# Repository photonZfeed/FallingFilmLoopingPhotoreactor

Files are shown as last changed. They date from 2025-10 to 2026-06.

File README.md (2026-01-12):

# Falling Film Looping Photoreactor and Residence Time Distribution Measurement Cells

A modular and characterized open source Falling Film Looping Photoreactor (FFLPR) concept for Automated Batch Stirred Tank Reactor (ABSTR) and Contineous Stirred Tank Reactor (CSTR) operation. And a Residence Time Distribution (RTD) cell for puls tracer measurements.

## Documentation

3D CAD files for the RTD cell manufacturing are documented in the [CAD section](./00_CAD/).

Experimental raw data on the RTD and bromination experiments are provided in the [Experiments section](./01_Experiments/).

A detailed documentation of the RTD cells and photoreactor including its control software as well as the RTD model are available under https://photonzfeed.github.io/FallingFilmLoopingPhotoreactor/.

## Folder Structure

```
📦Falling_Film_Loop_Photoreactor_RTD
┣ 📂 00_CAD
┃  ┣ 📜 RTD_cell_bottom_1mm_tubing.ipt
┃  ┣ 📜 RTD_cell_bottom_1mm_tubing.stl
┃  ┣ 📜 RTD_cell_bottom_2mm_tubing.ipt
┃  ┣ 📜 RTD_cell_bottom_2mm_tubing.stl
┃  ┣ 📜 RTD_cell_bottom_3mm_tubing.ipt
┃  ┣ 📜 RTD_cell_bottom_3mm_tubing.stl
┃  ┣ 📜 RTD_cell_top_1mm_tubing.ipt
┃  ┣ 📜 RTD_cell_top_1mm_tubing.stl
┃  ┣ 📜 RTD_cell_top_2mm_tubing.ipt
┃  ┣ 📜 RTD_cell_top_2mm_tubing.stl
┃  ┣ 📜 RTD_cell_top_3mm_tubing.ipt
┃  ┗ 📜 RTD_cell_top_3mm_tubing.stl
┣ 📂 01_Experiments
┃  ┣ 📂 00_RTD
┃  ┃  ┣ 📂 00_External_Flow_Rate_Variation
┃  ┃  ┃  ┣ 📜 03.3 mL per min.csv
┃  ┃  ┃  ┣ 📜 05 mL per min.csv
┃  ┃  ┃  ┣ 📜 10 mL per min.csv
┃  ┃  ┃  ┣ 📜 20 mL per min.csv
┃  ┃  ┃  ┗ 📜 40 mL per min.csv
┃  ┃  ┗ 📂 01_Space_Velocity_Variation
┃  ┃     ┣ 📜 0spv.csv
┃  ┃     ┣ 📜 15spv.csv
┃  ┃     ┣ 📜 30spv.csv
┃  ┃     ┗ 📜 5spv.csv
┃  ┗ 📂 01_Bromination
┃     ┣ 📂 00_CSTR_PLC_New_Column
┃     ┃  ┣ 📂 EXP-3 10 mLmin-1 external flow rate
┃     ┃  ┃  ┣ 📜 1.pdf
┃     ┃  ┃  ┣ 📜 10.pdf
┃     ┃  ┃  ┣ 📜 11.pdf
┃     ┃  ┃  ┣ 📜 12.pdf
┃     ┃  ┃  ┣ 📜 13.pdf
┃     ┃  ┃  ┣ 📜 14.pdf
┃     ┃  ┃  ┣ 📜 15.pdf
┃     ┃  ┃  ┣ 📜 2.pdf
┃     ┃  ┃  ┣ 📜 3.pdf
┃     ┃  ┃  ┣ 📜 4.pdf
┃     ┃  ┃  ┣ 📜 5.pdf
┃     ┃  ┃  ┣ 📜 6.pdf
┃     ┃  ┃  ┣ 📜 7.pdf
┃     ┃  ┃  ┣ 📜 8.pdf
┃     ┃  ┃  ┗ 📜 9.pdf
┃     ┃  ┣ 📂 EXP-4 20 mLmin-1 external flow rate
┃     ┃  ┃  ┣ 📜 1.pdf
┃     ┃  ┃  ┣ 📜 10.pdf
┃     ┃  ┃  ┣ 📜 11.pdf
┃     ┃  ┃  ┣ 📜 12.pdf
┃     ┃  ┃  ┣ 📜 13.pdf
┃     ┃  ┃  ┣ 📜 14.pdf
┃     ┃  ┃  ┣ 📜 15.pdf
┃     ┃  ┃  ┣ 📜 2.pdf
┃     ┃  ┃  ┣ 📜 3.pdf
┃     ┃  ┃  ┣ 📜 4.pdf
┃     ┃  ┃  ┣ 📜 5.pdf
┃     ┃  ┃  ┣ 📜 6.pdf
┃     ┃  ┃  ┣ 📜 7.pdf
┃     ┃  ┃  ┣ 📜 8.pdf
┃     ┃  ┃  ┗ 📜 9.pdf
┃     ┃  ┣ 📂 EXP-5 40 mLmin-1 external flow rate
┃     ┃  ┃  ┣ 📜 1.pdf
┃     ┃  ┃  ┣ 📜 10.pdf
┃     ┃  ┃  ┣ 📜 11`.pdf
┃     ┃  ┃  ┣ 📜 12.pdf
┃     ┃  ┃  ┣ 📜 13.pdf
┃     ┃  ┃  ┣ 📜 14.pdf
┃     ┃  ┃  ┣ 📜 15.pdf
┃     ┃  ┃  ┣ 📜 2.pdf
┃     ┃  ┃  ┣ 📜 3.pdf
┃     ┃  ┃  ┣ 📜 4.pdf
┃     ┃  ┃  ┣ 📜 5.pdf
┃     ┃  ┃  ┣ 📜 6.pdf
┃     ┃  ┃  ┣ 📜 7.pdf
┃     ┃  ┃  ┣ 📜 8.pdf
┃     ┃  ┃  ┗ 📜 9.pdf
┃     ┃  ┣ 📂 Scale-Up
┃     ┃  ┃  ┣ 📜 1.pdf
┃     ┃  ┃  ┣ 📜 10.pdf
┃     ┃  ┃  ┣ 📜 11.pdf
┃     ┃  ┃  ┣ 📜 12.pdf
┃     ┃  ┃  ┣ 📜 13.pdf
┃     ┃  ┃  ┣ 📜 14.pdf
┃     ┃  ┃  ┣ 📜 15.pdf
┃     ┃  ┃  ┣ 📜 2.pdf
┃     ┃  ┃  ┣ 📜 3.pdf
┃     ┃  ┃  ┣ 📜 4.pdf
┃     ┃  ┃  ┣ 📜 5.pdf
┃     ┃  ┃  ┣ 📜 6.pdf
┃     ┃  ┃  ┣ 📜 7.pdf
┃     ┃  ┃  ┣ 📜 8.pdf
┃     ┃  ┃  ┣ 📜 9.pdf
┃     ┃  ┃  ┗ 📜 BLANK.pdf
┃     ┃  ┣ 📂 Std. Graph
┃     ┃  ┃  ┣ 📜 BB1.1.pdf
┃     ┃  ┃  ┣ 📜 BB1.pdf
┃     ┃  ┃  ┣ 📜 BB2.pdf
┃     ┃  ┃  ┣ 📜 BB3.pdf
┃     ┃  ┃  ┣ 📜 BB4.pdf
┃     ┃  ┃  ┣ 📜 BB5.pdf
┃     ┃  ┃  ┣ 📜 BB6.pdf
┃     ┃  ┃  ┣ 📜 BB7.pdf
┃     ┃  ┃  ┣ 📜 BB8.pdf
┃     ┃  ┃  ┣ 📜 BB9.pdf
┃     ┃  ┃  ┗ 📜 BLANK.pdf
┃     ┃  ┗ 📜 readme.md
┃     ┣ 📂 01_CSTR_UV_VIS
┃     ┃  ┣ 📂 3 mLmin-1
┃     ┃  ┃  ┣ 📜 500 mM 3 mL-min.opju
┃     ┃  ┃  ┣ 📜 M1.txt
┃     ┃  ┃  ┣ 📜 R1.txt
┃     ┃  ┃  ┣ 📜 t=18.txt
┃     ┃  ┃  ┣ 📜 t=2.txt
┃     ┃  ┃  ┣ 📜 t=28.txt
┃     ┃  ┃  ┣ 📜 t=38.txt
┃     ┃  ┃  ┣ 📜 t=4.txt
┃     ┃  ┃  ┣ 📜 t=48.txt
┃     ┃  ┃  ┣ 📜 t=58.txt
┃     ┃  ┃  ┣ 📜 t=6.txt
┃     ┃  ┃  ┗ 📜 t=8.txt
┃     ┃  ┗ 📂 5 mLmin-1
┃     ┃     ┣ 📜 500mM 5mL-min.opju
┃     ┃     ┣ 📜 M2.txt
┃     ┃     ┣ 📜 R2.txt
┃     ┃     ┣ 📜 t=0.txt
┃     ┃     ┣ 📜 t=14.txt
┃     ┃     ┣ 📜 t=2.txt
┃     ┃     ┣ 📜 t=24.txt
┃     ┃     ┣ 📜 t=34.txt
┃     ┃     ┣ 📜 t=4.txt
┃     ┃     ┣ 📜 t=44.txt
┃     ┃     ┣ 📜 t=54.txt
┃     ┃     ┗ 📜 t=64.txt
┃     ┣ 📂 02_ABSTR_HPLC_Old_Column
┃     ┃  ┣ 📂 1 h reaction
┃     ┃  ┃  ┣ 📂 500 mM
┃     ┃  ┃  ┃  ┣ 📜 1.pdf
┃     ┃  ┃  ┃  ┣ 📜 10.pdf
┃     ┃  ┃  ┃  ┣ 📜 2.pdf
┃     ┃  ┃  ┃  ┣ 📜 3.pdf
┃     ┃  ┃  ┃  ┣ 📜 4.pdf
┃     ┃  ┃  ┃  ┣ 📜 5.pdf
┃     ┃  ┃  ┃  ┣ 📜 6.pdf
┃     ┃  ┃  ┃  ┣ 📜 7.pdf
┃     ┃  ┃  ┃  ┣ 📜 8.pdf
┃     ┃  ┃  ┃  ┗ 📜 9.pdf
┃     ┃  ┃  ┗ 📂 815 mM
┃     ┃  ┃     ┣ 📜 1.pdf
┃     ┃  ┃     ┣ 📜 2.pdf
┃     ┃  ┃     ┣ 📜 3.pdf
┃     ┃  ┃     ┣ 📜 4.pdf
┃     ┃  ┃     ┣ 📜 5.pdf
┃     ┃  ┃     ┣ 📜 6.pdf
┃     ┃  ┃     ┣ 📜 7.pdf
┃     ┃  ┃     ┗ 📜 8.pdf
┃     ┃  ┣ 📂 24 h reactions
┃     ┃  ┃  ┣ 📂 500 mM scale
┃     ┃  ┃  ┃  ┣ 📜 1.pdf
┃     ┃  ┃  ┃  ┣ 📜 2.pdf
┃     ┃  ┃  ┃  ┣ 📜 3.pdf
┃     ┃  ┃  ┃  ┣ 📜 4.pdf
┃     ┃  ┃  ┃  ┣ 📜 5.pdf
┃     ┃  ┃  ┃  ┣ 📜 6.pdf
┃     ┃  ┃  ┃  ┗ 📜 7.pdf
┃     ┃  ┃  ┗ 📂 815 mM scale
┃     ┃  ┃     ┣ 📜 1.pdf
┃     ┃  ┃     ┣ 📜 2.pdf
┃     ┃  ┃     ┣ 📜 3.pdf
┃     ┃  ┃     ┣ 📜 4.pdf
┃     ┃  ┃     ┣ 📜 5.pdf
┃     ┃  ┃     ┣ 📜 6.pdf
┃     ┃  ┃     ┗ 📜 7.pdf
┃     ┃  ┣ 📂 different internal flow rate
┃     ┃  ┃  ┣ 📂 500 mM with out looping operation
┃     ┃  ┃  ┃  ┣ 📜 1.pdf
┃     ┃  ┃  ┃  ┣ 📜 2.pdf
┃     ┃  ┃  ┃  ┣ 📜 3.pdf
┃     ┃  ┃  ┃  ┣ 📜 4.pdf
┃     ┃  ┃  ┃  ┣ 📜 5.pdf
┃     ┃  ┃  ┃  ┗ 📜 6.pdf
┃     ┃  ┃  ┣ 📂 500 mM-space velocity 150 min-1
┃     ┃  ┃  ┃  ┣ 📜 1.pdf
┃     ┃  ┃  ┃  ┣ 📜 2.pdf
┃     ┃  ┃  ┃  ┣ 📜 3.pdf
┃     ┃  ┃  ┃  ┣ 📜 4.pdf
┃     ┃  ┃  ┃  ┣ 📜 5.pdf
┃     ┃  ┃  ┃  ┗ 📜 6.pdf
┃     ┃  ┃  ┣ 📂 500 mM-space velocity 300 min-1
┃     ┃  ┃  ┃  ┣ 📜 1.pdf
┃     ┃  ┃  ┃  ┣ 📜 2.pdf
┃     ┃  ┃  ┃  ┣ 📜 3.pdf
┃     ┃  ┃  ┃  ┣ 📜 4.pdf
┃     ┃  ┃  ┃  ┣ 📜 5.pdf
┃     ┃  ┃  ┃  ┗ 📜 6.pdf
┃     ┃  ┃  ┗ 📂 800 mM with out looping operation
┃     ┃  ┃     ┣ 📜 1.pdf
┃     ┃  ┃     ┣ 📜 2.pdf
┃     ┃  ┃     ┣ 📜 3.pdf
┃     ┃  ┃     ┣ 📜 4.pdf
┃     ┃  ┃     ┣ 📜 5.pdf
┃     ┃  ┃     ┗ 📜 6.pdf
┃     ┃  ┣ 📂 Optimization with respect to different concentration
┃     ┃  ┃  ┣ 📂 500 mM
┃     ┃  ┃  ┃  ┣ 📜 1.1.pdf
┃     ┃  ┃  ┃  ┣ 📜 1.2.pdf
┃     ┃  ┃  ┃  ┣ 📜 1.3.pdf
┃     ┃  ┃  ┃  ┣ 📜 1.4.pdf
┃     ┃  ┃  ┃  ┣ 📜 1.5.pdf
┃     ┃  ┃  ┃  ┗ 📜 1.6.pdf
┃     ┃  ┃  ┗ 📂 815 mM
┃     ┃  ┃     ┣ 📜 4.1.pdf
┃     ┃  ┃     ┣ 📜 4.2.pdf
┃     ┃  ┃     ┣ 📜 4.3.pdf
┃     ┃  ┃     ┣ 📜 4.4.pdf
┃     ┃  ┃     ┣ 📜 4.5.pdf
┃     ┃  ┃     ┗ 📜 4.7.pdf
┃     ┃  ┣ 📂 Scale-Up
┃     ┃  ┃  ┣ 📜 1.pdf
┃     ┃  ┃  ┣ 📜 2.pdf
┃     ┃  ┃  ┣ 📜 3.pdf
┃     ┃  ┃  ┣ 📜 4.pdf
┃     ┃  ┃  ┣ 📜 5.pdf
┃     ┃  ┃  ┣ 📜 6.pdf
┃     ┃  ┃  ┣ 📜 7.pdf
┃     ┃  ┃  ┣ 📜 8.pdf
┃     ┃  ┃  ┣ 📜 9.pdf
┃     ┃  ┃  ┗ 📜 BLANK.pdf
┃     ┃  ┗ 📂 Std. Graph
┃     ┃     ┣ 📜 1.25.pdf
┃     ┃     ┣ 📜 10.pdf
┃     ┃     ┣ 📜 160.pdf
┃     ┃     ┣ 📜 2.5.pdf
┃     ┃     ┣ 📜 20.pdf
┃     ┃     ┣ 📜 320.pdf
┃     ┃     ┣ 📜 40.pdf
┃     ┃     ┣ 📜 5.pdf
┃     ┃     ┣ 📜 80.pdf
┃     ┃     ┗ 📜 blank.pdf
┃     ┗ 📂 03_ABSTR_UV_Vis
┃        ┣ 📂 500 mM
┃        ┃  ┣ 📜 1.0.txt
┃        ┃  ┣ 📜 1.1.txt
┃        ┃  ┣ 📜 1.2.txt
┃        ┃  ┣ 📜 1.3.txt
┃        ┃  ┣ 📜 1.4.txt
┃        ┃  ┣ 📜 1.5.txt
┃        ┃  ┣ 📜 1.6.txt
┃        ┃  ┣ 📜 benzyl bromide.txt
┃        ┃  ┣ 📜 reaction kinetics 500mM.opju
┃        ┃  ┗ 📜 toluene.txt
┃        ┣ 📂 515 mM scale
┃        ┃  ┣ 📜 1.txt
┃        ┃  ┣ 📜 2.txt
┃        ┃  ┣ 📜 3.txt
┃        ┃  ┣ 📜 4.txt
┃        ┃  ┣ 📜 5.txt
┃        ┃  ┣ 📜 6.txt
┃        ┃  ┣ 📜 reaction kinetics 815 mM final.opju
┃        ┃  ┗ 📜 reaction mixture.txt
┃        ┗ 📂 BB and Toluene
┃           ┣ 📜 benzyl bromide.txt
┃           ┗ 📜 toluene.txt
┣ 📂 02_Software
┃  ┣ 📂 00_RTD_Model
┃  ┃  ┣ 📂 00_Processed_Data
┃  ┃  ┃  ┣ 📜 10 mL per min processed.csv
┃  ┃  ┃  ┣ 📜 20 mL per min processed.csv
┃  ┃  ┃  ┣ 📜 3.3 mL per min processed.csv
┃  ┃  ┃  ┣ 📜 40 mL per min processed.csv
┃  ┃  ┃  ┣ 📜 5 mL per min processed.csv
┃  ┃  ┃  ┗ 📜 summary_table.csv
┃  ┃  ┣ 📂 01_Figures
┃  ┃  ┃  ┣ 📜 all_simulated_RTDs_plot.png
┃  ┃  ┃  ┣ 📜 comparison_plot.png
┃  ┃  ┃  ┗ 📜 tau_Bo_plot.png
┃  ┃  ┣ 📜 main.ipynb
┃  ┃  ┗ 📜 README.md
┃  ┣ 📂 01_Arduino_Control
┃  ┃  ┣ 📂 lib
┃  ┃  ┃  ┣ 📜 HX711_ADC-master.zip
┃  ┃  ┃  ┗ 📜 LiquidCrystal_I2C-master.zip
┃  ┃  ┣ 📜 bstr.ino
┃  ┃  ┣ 📜 cstr.ino
┃  ┃  ┗ 📜 readme.md
┃  ┗ 📜 02_RTD_Cell_Control.py
┣ 📂 03_Documentation
┃  ┗ 📜 RTD_cell_Dani_merge.rst
┣ 📜 .gitignore
┣ 📜 README.md
┗ 📜 requirements.txt
```

## Publications
The FFLPR concept was verfied using the light-driven and N-Bromsuccinimid mediated allyic bromination of toluene as model reaction.

A detailed documentation of the FFLPR modules and optical charazterization data can be found in the following publication:
* [Making photochemistry scalable – an operationally simple falling film looping photoreactor](https://pubs.rsc.org/en/content/articlelanding/2023/re/d3re00107e)

A comparative evaluation of scale up strategies of the FFLPR for ABSTR and CSTR operation is described in the following publication:
* [A Comparative Experimental Evaluation of an Automated Batchwise and Continuous Operation Mode for Scaling Up a Falling Film Looping Photoreactor](https://fill_in_the_blank)

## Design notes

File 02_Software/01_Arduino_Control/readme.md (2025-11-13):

## HX711 Load Cell Project — bstr & cstr

This project contains two Arduino sketches, bstr and cstr, which utilize the HX711_ADC library to interface with HX711 load cell amplifiers for weight measurement. Additionally, an I2C Liquid Crystal Display (LCD) is used to show readings and status messages. The sketches are programmed using the Arduino IDE and require both the HX711_ADC and LiquidCrystal_I2C libraries.

The HX711_ADC library is licensed under the MIT License. See the library repository for details.

 - [HX711 LOAD CELL LIBRARY REPOSITORY](https://github.com/olkal/HX711_ADC)
 - [LiquidCrystal_I2C](https://github.com/johnrickman/LiquidCrystal_I2C.git)

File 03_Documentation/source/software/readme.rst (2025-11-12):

============================================================
HX711 Load Cell Project — BSTR & CSTR
============================================================

Project Overview
================

This project contains two Arduino sketches designed for **Batch Stirred Tank Reactor (BSTR)** and **Continuous Stirred Tank Reactor (CSTR)** systems. Both sketches utilize the HX711_ADC library to interface with HX711 load cell amplifiers for precise weight measurement and mass monitoring.

The project integrates an I2C Liquid Crystal Display (LCD) for real-time display of sensor readings and system status messages. All sketches are programmed using the Arduino IDE and require installation of the HX711_ADC and LiquidCrystal_I2C libraries.

System Components
=================

**Arduino Sketches:**

* **BSTR Sketch:** Batch Stirred Tank Reactor control system
* **CSTR Sketch:** Continuous Stirred Tank Reactor with automated inlet/outlet valve control

**Hardware Requirements:**

* HX711 Load Cell Amplifier
* Digital Load Cell Sensor (weight transducer)
* 16x2 I2C LCD Display
* Arduino microcontroller (compatible board)
* Inlet and outlet control valves
* Tare/reset button

**Software Libraries:**

* HX711_ADC - Load cell amplifier interface library
* LiquidCrystal_I2C - I2C LCD display control library
* Wire - Arduino I2C communication protocol

Dependencies and Installation
=============================

The following libraries are required for this project:

**HX711_ADC Library**

The HX711_ADC library provides the interface for communicating with HX711 load cell amplifiers. This library is licensed under the MIT License.

Repository: https://github.com/olkal/HX711_ADC

**LiquidCrystal_I2C Library**

The LiquidCrystal_I2C library enables control of 16x2 LCD displays via I2C protocol, simplifying wiring and communication.

Repository: https://github.com/johnrickman/LiquidCrystal_I2C.git

**Installation:**

Install both libraries through the Arduino IDE Library Manager or by cloning the repositories into your local Arduino libraries directory.

Features
========

**Load Cell Measurement:**

* Precise mass monitoring using HX711 amplifier
* Calibration support with standard weights
* Real-time weight display on LCD

**Display Interface:**

* 16x2 LCD display with I2C address configuration (0x27)
* Unit conversion (grams to ounces)
* Status messages and system feedback

**CSTR Automated Control:**

* Automatic inlet/outlet valve regulation based on mass thresholds
* Configurable weight setpoints
* Overload protection and alarm functionality

**Data Processing:**

* Weight filtering and stabilization
* Conversion between measurement units
* Threshold-based control logic

Project Structure
=================

The project consists of the following files:

* bstr.ino - Batch Stirred Tank Reactor control sketch
* cstr.ino - Continuous Stirred Tank Reactor control sketch
* readme.md - Project documentation

License
=======

The HX711_ADC library is licensed under the MIT License. Please refer to the library repository for detailed license information and terms.

Notes
=====

* Calibrate the load cell using a standard 100g weight before deployment
* Configure the I2C LCD address (default: 0x27) according to your hardware setup
* Adjust the calibration factor in the code based on your specific load cell specifications
* Ensure proper wiring of all I2C devices to avoid communication errors
* Use appropriate power supply ratings for the Arduino and peripheral devices

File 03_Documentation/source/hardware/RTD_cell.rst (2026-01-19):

Residence Time Distribution Measurement Cell
============================================

Required 3D-Printed Components (Click to Download)
---------------------------------------------------
-   `2x Analytic cells (2 LED halfcells, 2 photoresistor halfcells, available with 1, 2 and 3 mm inner diameter) <https://github.com/photonZfeed/FallingFilmLoopingPhotoreactor/tree/main/00_CAD>`_
-   `base plate bricklet casing <../_static/cad/base_plate.stl>`_

Required Hardware Components
-------------------------------

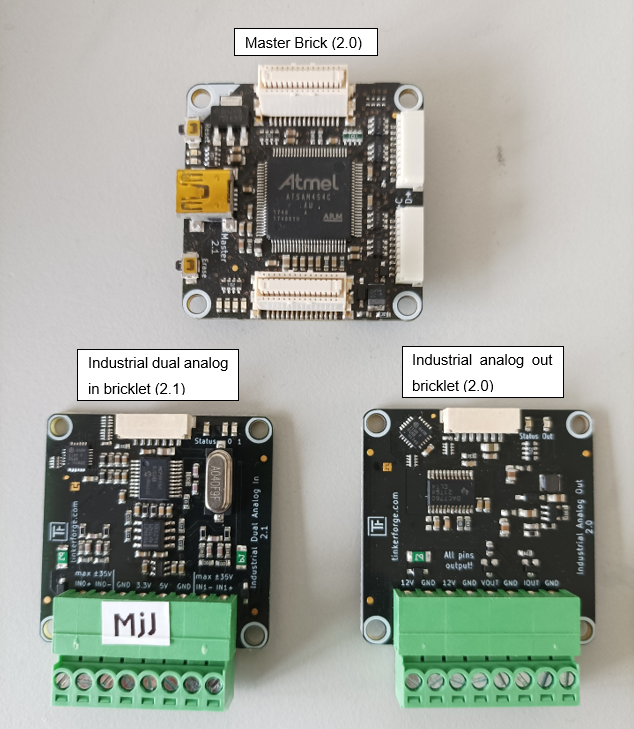
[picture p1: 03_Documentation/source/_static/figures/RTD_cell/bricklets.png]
Required Bricklets.


-	`Master brick (2.0) <https://www.tinkerforge.com/en/doc/Hardware/Bricks/Master_Brick.html>`_
-	`Industrial analog out bricklet (2.0) <https://www.tinkerforge.com/de/shop/industrial-analog-out-v2-bricklet.html>`_
-	`Industrial analog in bricklet (2.1) <https://www.tinkerforge.com/de/shop/industrial-dual-analog-in-v2-bricklet.html>`_
-	External power supply
-	USB-A to USB-C cable
-	2x LEDs
- `2 x photoresistors <materials/00_Electronics/06_Other_Small_Parts/photoresistor.rst>`_
-	2x Resistors (10 kΩ)
-	2x Connections between in/out and master brick
-	2x small screws for the top of the analytic cells (M3)
-	8x screws for the sides of the analytic cells (M3)
-	8x Nuts (+2x nuts in the analytic halfcells for the LEDs)
-  electrical wire (preferably in 2 different colors)
-  (Through connectors for photoresistors, resistors and electrical wire / Electrical insulating tapes)

Assembly Instructions
------------------------

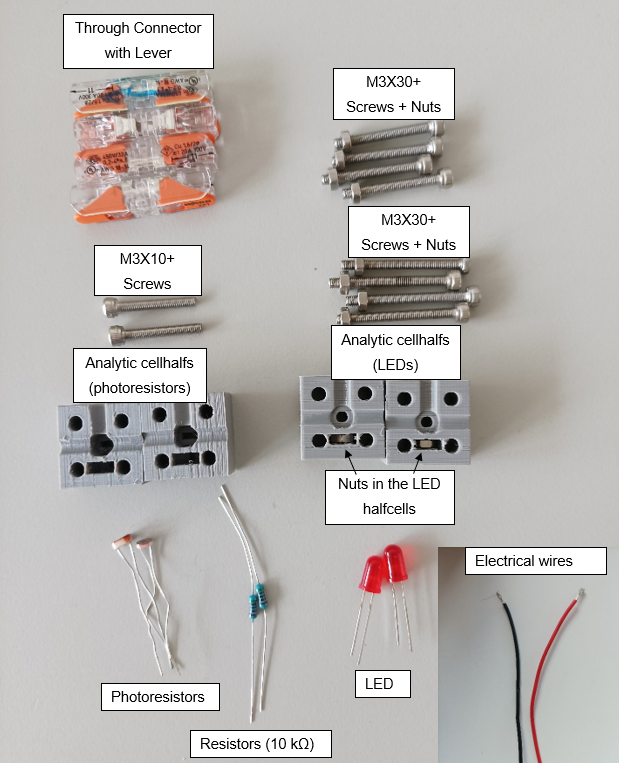
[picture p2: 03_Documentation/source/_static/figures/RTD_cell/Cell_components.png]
Components for connecting the analytic cells.


   Figure 1: Components for connecting the analytic cells.

1. Put the LEDs in the LED halfcells on the outside of the cells (backside of the cells in the figure).
2. Screw one of the small screws on the top of the LED halfcell to fix the LED in the cell. (Make sure a nut is placed in the slid of the halfcell).
3. Put the photoresistors in the photoresistor half cells (photoresistor in the whole, wires to the outside of the cell).
4. Use the bigger screws to fix one LED to a photoresistor halfcell and repeat with the other cells.

Bricklets for the setup

   Figure 2: Bricklets for the setup

5. Connect the photoresistors to the industrial dual analog in bricklet as shown in Figure 2 with the electrical wires. 
   Make sure to separate the wires apart from the shown connections using the through connectors and/or electrical insulating tape.

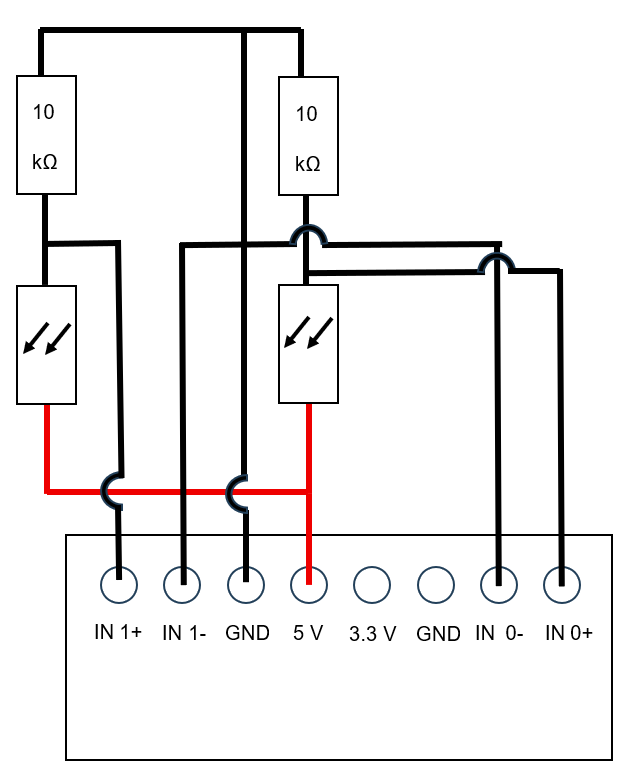
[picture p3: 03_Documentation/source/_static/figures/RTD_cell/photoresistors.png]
Sketch on how to connect the photoresistors to the bricklet.


   Figure 3: Sketch on how to connect the photoresistors to the bricklet.

6. Connect the LEDs to the industrial analog out bricklet as shown in Figure 3 with the electrical wires.

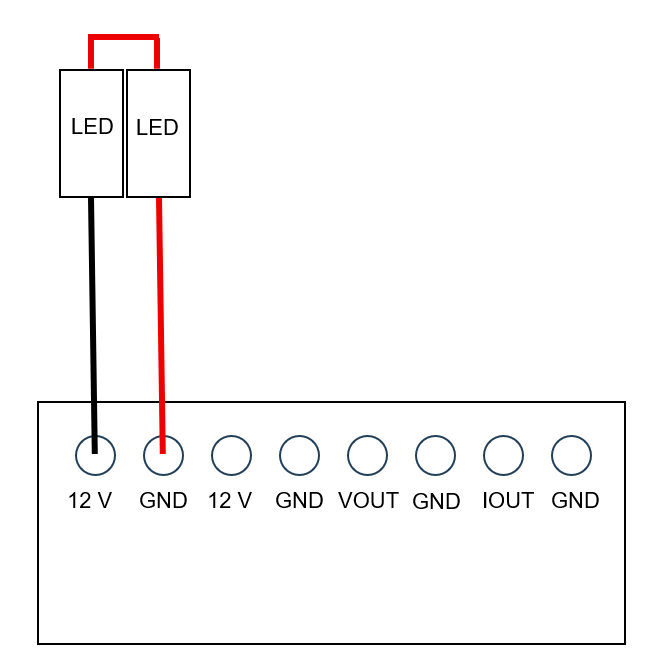
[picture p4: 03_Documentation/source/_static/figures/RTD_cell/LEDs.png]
Sketch on how to connect the LEDs to the bricklet.


   Figure 4: Sketch on how to connect the LEDs to the bricklet.

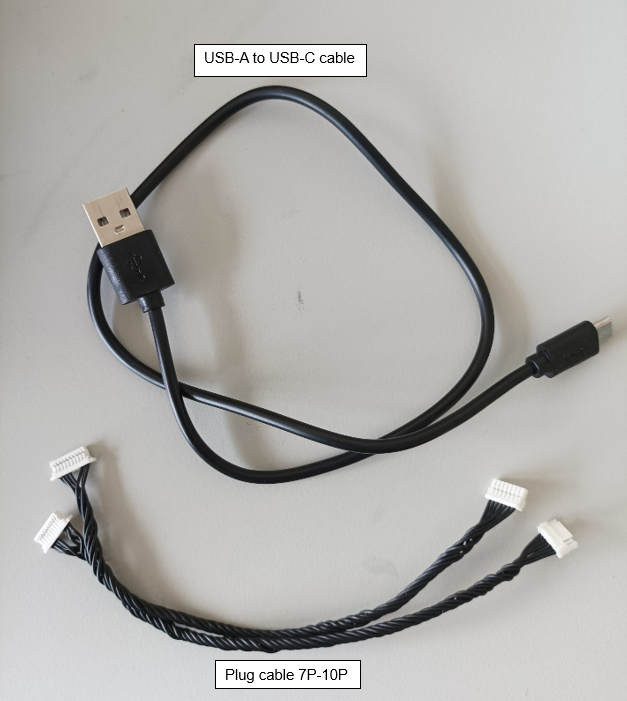
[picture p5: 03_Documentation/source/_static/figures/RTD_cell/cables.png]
Cables to connect the bricklets.


   Figure 5: Cables to connect the bricklets.

7. Connect the industrial dual analog in and the industrial analog out bricklets to the master brickletr using the Plug cable 7P-10P.

The setup should look like this afterwards:

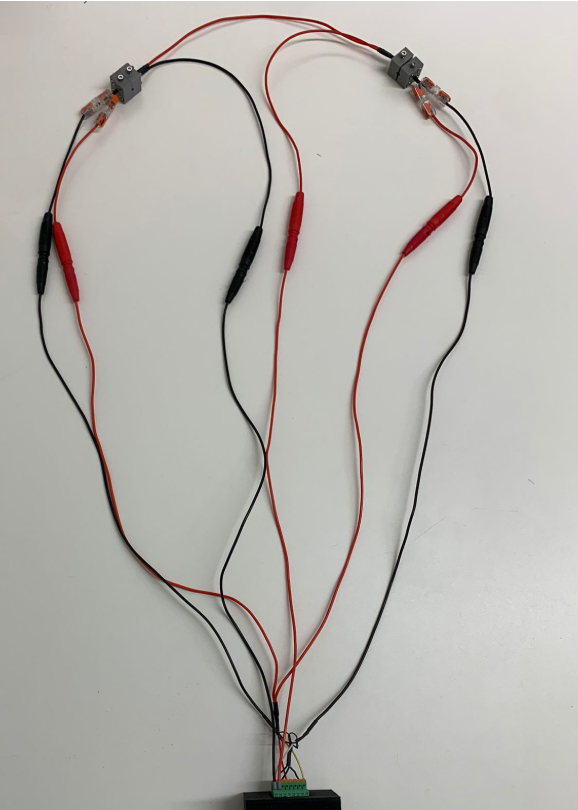
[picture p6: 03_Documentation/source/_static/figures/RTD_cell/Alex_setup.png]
Example setup.


   Figure 6: Example setup.

Operation
------------

Setup
^^^^^^^^

First the setup needs to be connected to a PC with the USB-A to USB-C cable.
For the residence time distribution measurements, one cell has to be fixed on the capillary before and one after the reactor.
As a tracer for the measurement, Methylene Blue with a concentration of 1 g/L for an aqueous system or 0.8 g/L in acetonitrile is suggested.

Code 
^^^^^^

To operate the setup, the following code is needed: Dynamic_Plot_new.py 
The code is available here: https://github.com/photonZfeed/FallingFilmLoopingPhotoreactor/blob/main/02_Software/02_RTD_Cell_Control.py.
Make sure all needed packages for the code are installed and the UID for industrial analog in and out in the code is changed to the once used in the setup.
The UIDs for industrial analog in and out can be checked with brickviewer, once the setup is connected to the PC.
To open the measurement window, run the code.
The following window should open:

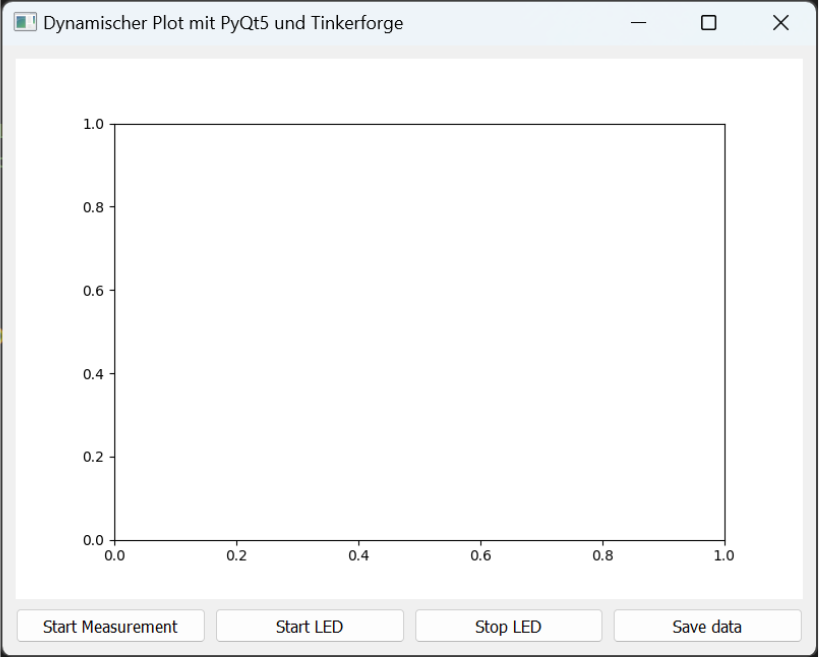
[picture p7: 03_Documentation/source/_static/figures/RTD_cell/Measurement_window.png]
Measurement window.


   Figure 7: Measurement window.

Before measurement can start the LEDs must be turned on for at least 60 sec. by pressing "Start LED".
This is to ensure a stable signal from the photoresistors before measurements start.
Clicking "Start Measurement" will start the Liveplot and the "Save data" button allows to save the data from the measurement.

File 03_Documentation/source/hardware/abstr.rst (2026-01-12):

Automated Batch Stirred Tank Reactor (ABSTR)
============================================

OVERVIEW
--------

The automated batch stirred tank reactor (ABSTR) is a software-controlled system that performs cyclic pump operations for continuous photoreactor processing. It sequentially delivers reaction mixture, collects product, washes with solvent, and repeats automatically. Programmable control enables precise timing, adaptable parameters, and reliable, continuous reactor operation.       

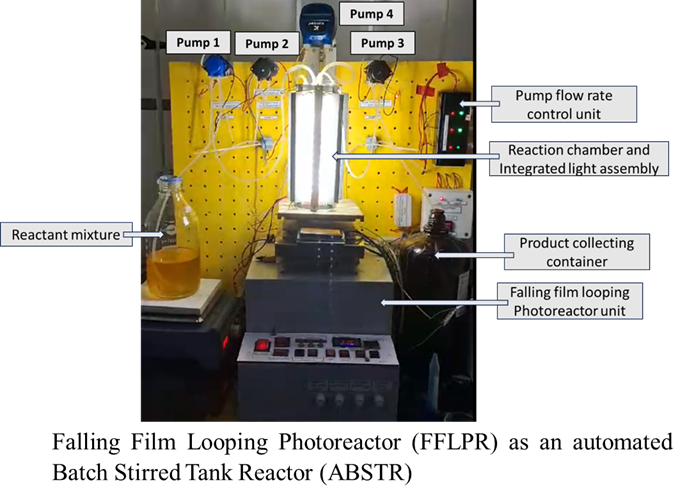
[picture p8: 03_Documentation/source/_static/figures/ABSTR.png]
complete image


   Figure 1: Complete diagram of the machine

MODULES USED
------------
:doc:`Time controller module <materials/01_Accessories/time_controller>`

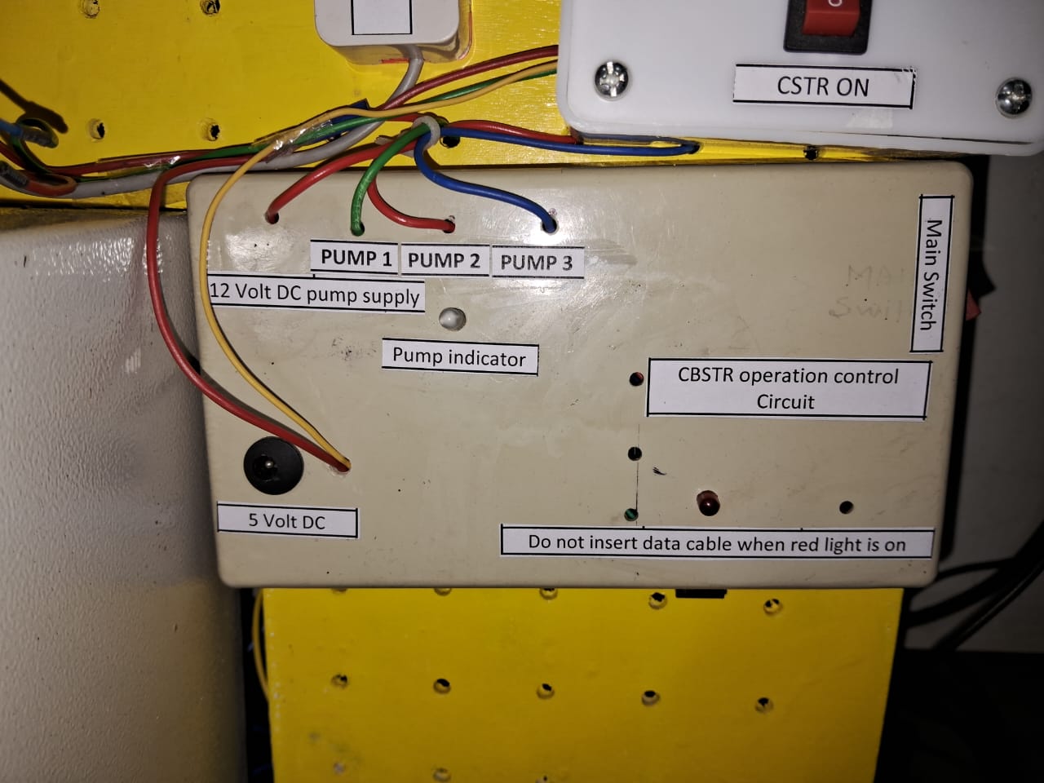
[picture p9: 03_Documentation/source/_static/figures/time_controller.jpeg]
time controller module


:doc:`Transit Circuit <materials/01_Accessories/transit_ckt>`

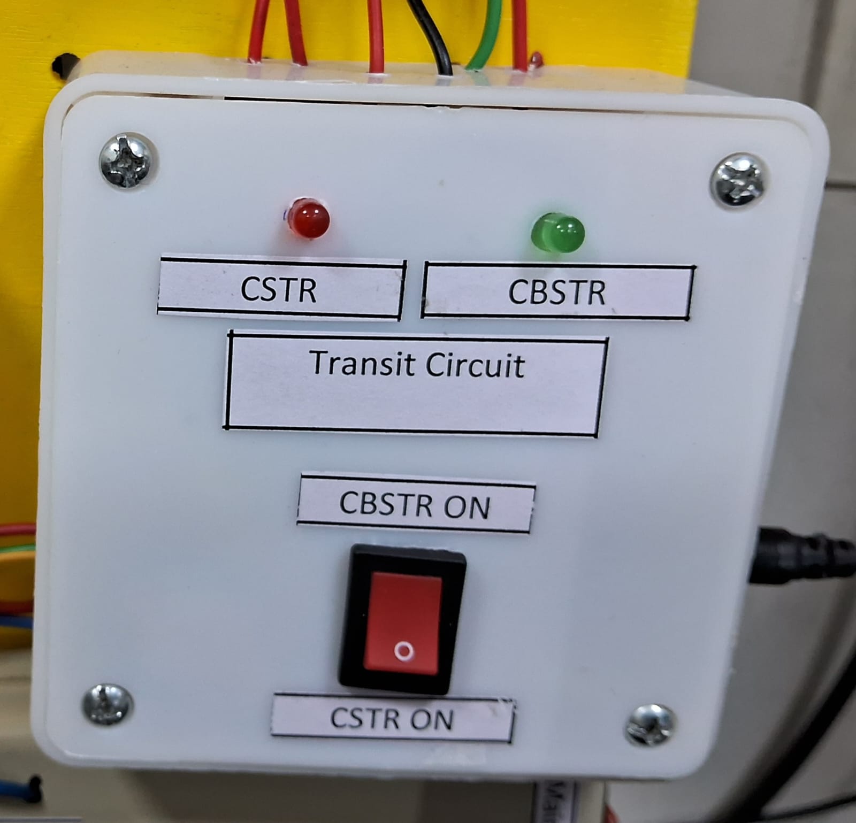
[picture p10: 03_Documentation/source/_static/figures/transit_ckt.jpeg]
transit circuit module


:doc:`Power Supply <materials/00_Electronics/02_Power_Supplies/12V_10A>`

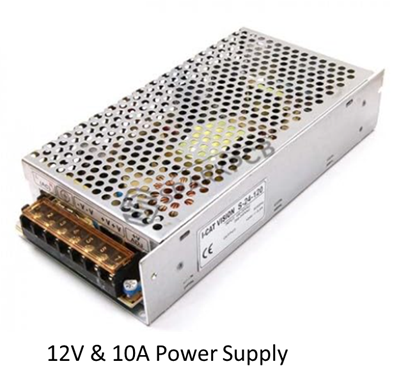
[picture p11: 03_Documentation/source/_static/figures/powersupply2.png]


Connection Instructions
-----------------------
1.Connect the output terminal of the controller to the input terminal of the pump controller to enable software-based actuation.

2.Connect the output terminals of the pump controller individually to each pump for independent operation.

3.Connect the ground of each pump and combine them to form a common ground, then interface this common ground with the power supply ground.

4.Connect the power supply to the pump controller to provide stable operating power.

5.Connect the power supply to the timing controller module to ensure proper timing and sequencing functionality.

6.Refer to the block diagram provided below for a clearer understanding of the overall system architecture and signal flow.

7.After that uplod the arduino code given below after adjusting the parameters required for the timers.

Block Diagram
-------------
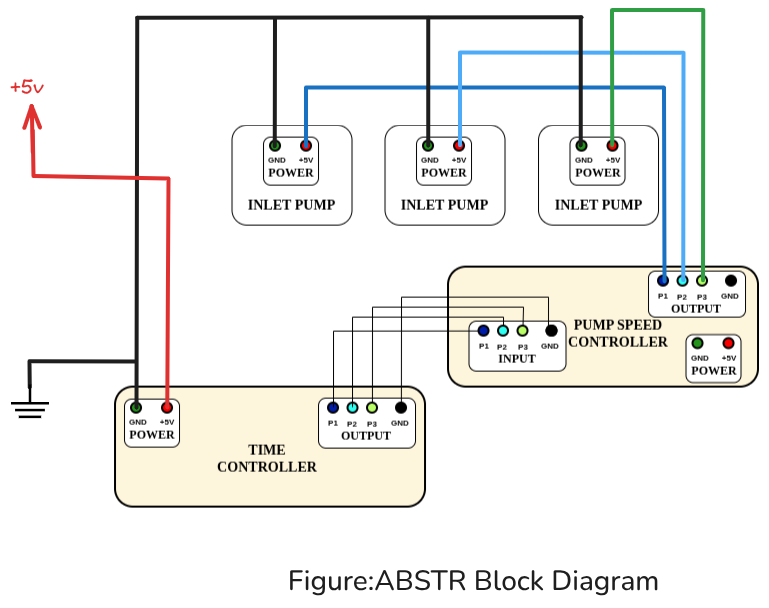
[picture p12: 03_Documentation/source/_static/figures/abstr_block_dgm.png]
block diagram


Arduino code For ABSTR
----------------------

.. code-block:: cpp
   :linenos:

   int A;
   int B;
   int C;
   int D;

   void setup() {
      pinMode(2, OUTPUT);
      pinMode(3, OUTPUT);
      pinMode(4, OUTPUT);
   }

   void loop() {
      A = (10UL * 1UL * 1000UL);
      B = (10UL * 1UL * 1000UL);
      D = (10UL * 1UL * 1000UL);

      digitalWrite(2, HIGH);
      digitalWrite(3, LOW);
      digitalWrite(4, LOW);
      delay(A);

      digitalWrite(2, LOW);
      digitalWrite(3, HIGH);
      delay(B);

      digitalWrite(2, HIGH);
      digitalWrite(3, LOW);
      delay(A);

      digitalWrite(2, LOW);
      digitalWrite(4, HIGH);
      delay(D);

      digitalWrite(4, LOW);
      digitalWrite(7, HIGH);
      delay(60UL * 12UL * 1000UL);

      digitalWrite(7, LOW);
      digitalWrite(LED_BUILTIN, HIGH);
   }

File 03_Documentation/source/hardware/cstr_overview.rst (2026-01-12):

Continuous Batch Stirred Tank Reactor (CSTR)
============================================

OVERVIEW
--------
The continuous batch stirred tank reactor (CSTR) is a software-assisted system designed to operate continuously while maintaining controlled flow rates and stable reactor volume. It uses dedicated inlet, outlet, and looping pumps to regulate mass, recirculate reactor effluent, and sustain a falling-film stirring environment. Through predefined flow parameters and dynamic feedback from an integrated weighing scale, the control software modulates pump operation to keep the reactor mass within target limits. Adjustable experimental settings allow the system to be optimized for different reaction conditions, ensuring stable, scalable, and efficient continuous operation.

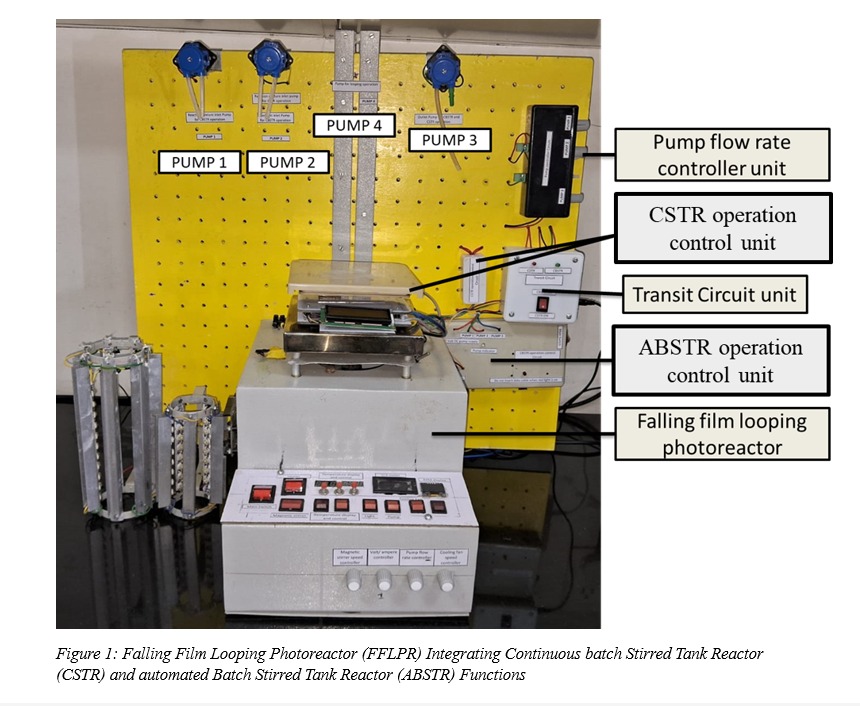
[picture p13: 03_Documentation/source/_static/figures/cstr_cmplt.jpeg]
complete image


   Figure 1: Complete diagram of the machine

MODULES USED
------------

:doc:`Measurement Module<materials/01_Accessories/weigh_scale>`

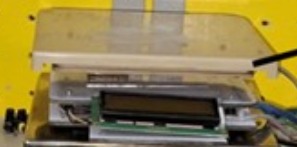
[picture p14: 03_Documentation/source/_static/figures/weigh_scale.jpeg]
Measurement Module


:doc:`Power Supply <materials/00_Electronics/02_Power_Supplies/12V_10A>`

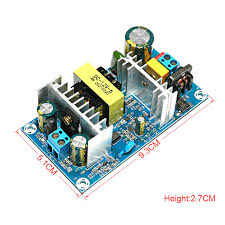
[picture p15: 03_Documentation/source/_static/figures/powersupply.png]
power supply module


:doc:`PUMP SPEED CONTROLLER <materials/01_Accessories/pump_controller>`

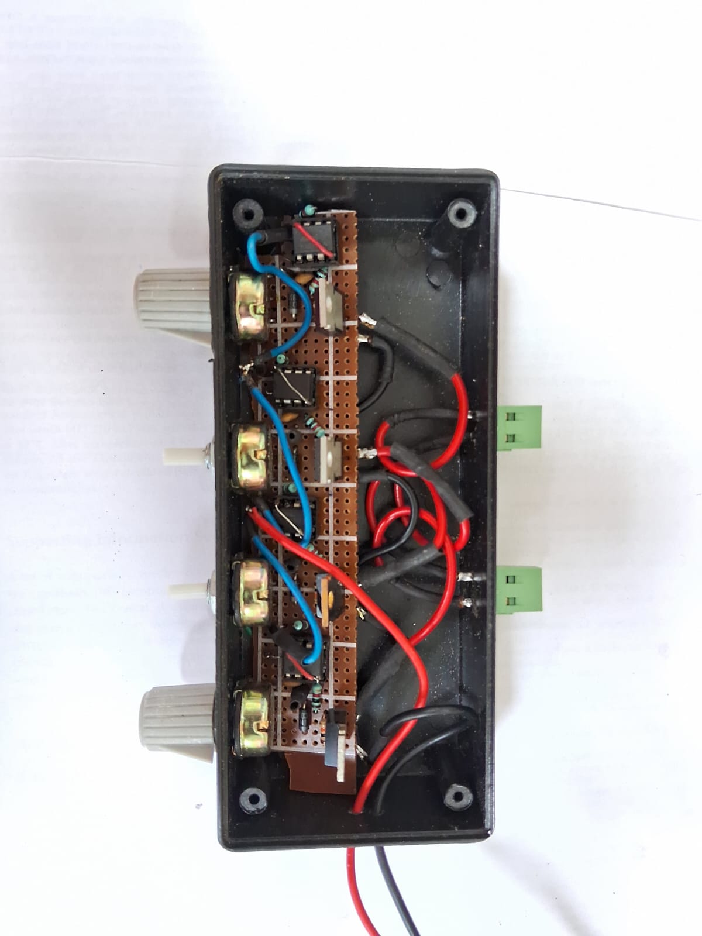
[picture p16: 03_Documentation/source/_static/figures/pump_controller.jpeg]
pump speed controller


:doc:`Transit Circuit <materials/01_Accessories/transit_ckt>`

transit circuit module

:doc:`CSTR OPERATIONAL CKT <materials/01_Accessories/cstr_operational_ckt>`

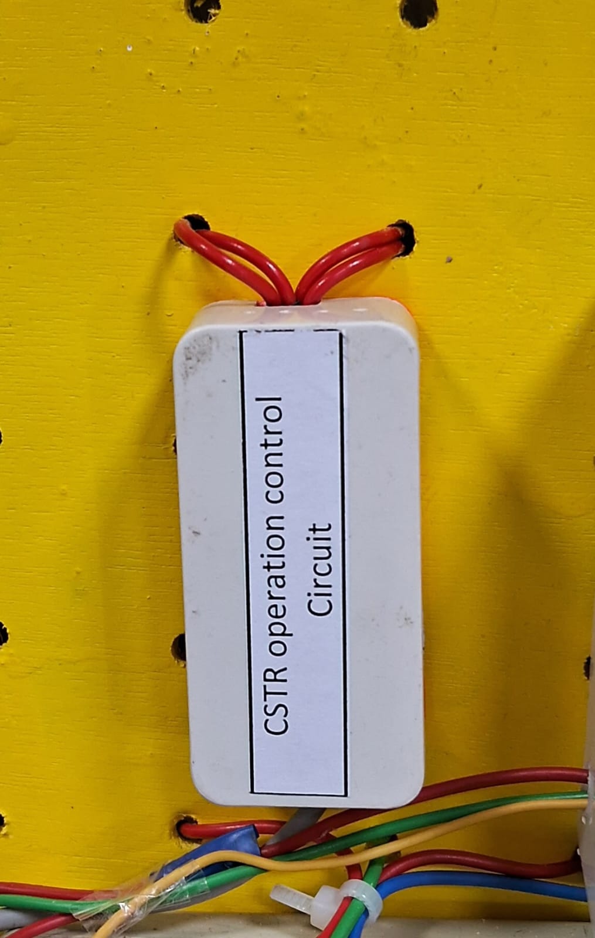
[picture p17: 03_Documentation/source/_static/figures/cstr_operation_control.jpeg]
cstr operational circuit


:doc:`Low Flow Peristaltic Pump <materials/01_Accessories/perisstalticpump_lowflow>`

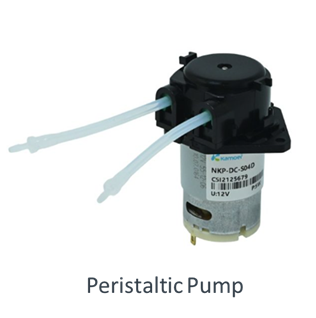
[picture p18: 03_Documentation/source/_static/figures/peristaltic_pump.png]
low flow peristaltic pump


:doc:`High Flow Peristaltic Pump <materials/01_Accessories/peristalticpump_highflow>`

high flow peristaltic pump

Assembly Instruction
--------------------

1.Connect the Power of the measurement scale with the adapter

2.connect the output of the measurement scale with the input of the cstr operational circuit according to block diagram below

3.connect the power of the cstr operational module.

4.connect the inlet and outlet pump with the cstr operational circuit according to the block diagram below.

5.Connect the ground of all the modules to form a common ground.

1. Refer to the block diagram provided below for a clearer understanding of the overall system architecture and signal flow.

2. Upload the arduino code given below after adjusting the parameters required for the weighing scale and pumps.

Block Diagram
-------------

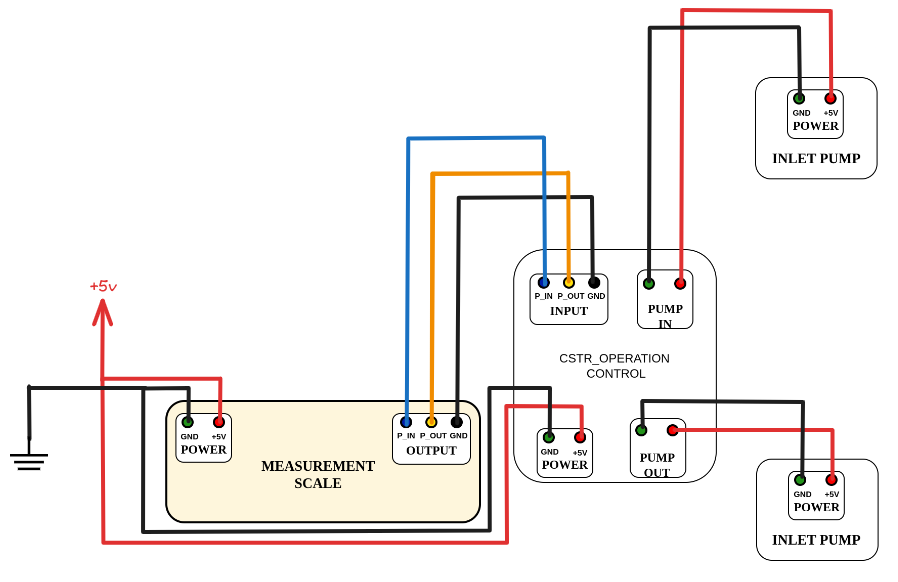
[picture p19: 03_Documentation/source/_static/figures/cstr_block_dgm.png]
cstr block diagram


   Figure: Block diagram of CSTR circuit

Arduino Code for CSTR
---------------------

.. code-block:: cpp
   :linenos:

   #include <HX711_ADC.h>
   #include <Wire.h>
   #include <LiquidCrystal_I2C.h> // LiquidCrystal_I2C library

   HX711_ADC LoadCell(4, 5);  // dt pin, sck pin
   LiquidCrystal_I2C lcd(0x27, 16, 2); // LCD HEX address 0x27

   int taree = 6;
   int a = 0;
   float b = 0;
   int inlet = 7;
   int outlet = 8;

   int max = 20.5 // set the maximum weight of the reactant
   int min = 19.5 // set the minimum weight of the reactant

   void setup() {
      pinMode(inlet, OUTPUT);
      pinMode(outlet, OUTPUT);
      pinMode(taree, INPUT_PULLUP);

      LoadCell.begin(); // start connection to HX711
      LoadCell.start(1000); // load cells get 1000ms of time to stabilize

      ///////////////////////////////////////////
      LoadCell.setCalFactor(375); // Calibrate your LOAD CELL with 100g weight,
                                 // and change the value according to readings
      ///////////////////////////////////////////

      // initialize the LCD
      lcd.begin();      // begins connection to the LCD module
      lcd.backlight();  // turns on the backlight
      lcd.setCursor(1, 0); // set cursor to first row
      lcd.print("Digital Scale "); // print out to LCD
      lcd.setCursor(0, 1); // set cursor to first row
      lcd.print(" SHIBU NASKAR "); // print out to LCD
      delay(3000);
      lcd.clear();
   }

   void loop() {
      lcd.setCursor(1, 0); // set cursor to first row
      lcd.print("Digital Scale "); // print out to LCD

      LoadCell.update(); // retrieves data from the load cell
      float i = LoadCell.getData(); // get output value

      if (i < 0) {
         i = i * (-1);
         lcd.setCursor(0, 1);
         lcd.print(" ");
         lcd.setCursor(8, 1);
         lcd.print(" ");
      } else {
         lcd.setCursor(0, 1);
         lcd.print(" ");
         lcd.setCursor(8, 1);
         lcd.print(" ");

         lcd.setCursor(1, 1); // set cursor to second row
         lcd.print(i); // print out the retrieved value to the second row
         lcd.print("g ");
         float z = i / 28.3495;
         lcd.setCursor(9, 1);
         lcd.print(z, 2);
         lcd.print("oz ");

         if (i > 5000) {
               i = 0;
               lcd.setCursor(0, 0); // set cursor to second row
               lcd.print(" Over loaded ");
               delay(200);
         }

         if (i > max) {
               digitalWrite(outlet, HIGH);
               delay(10);
               digitalWrite(inlet, LOW);
               delay(800);
         } else if (i < min) {
               digitalWrite(inlet, HIGH);
               delay(10);
               digitalWrite(outlet, LOW);
               delay(800);
         } else if (i >= min && i <= max) {
               digitalWrite(outlet, HIGH);
               digitalWrite(inlet, HIGH);
               delay(800);
         } else {
               digitalWrite(outlet, LOW);
               digitalWrite(inlet, LOW);
               delay(800);
         }
      }
   }

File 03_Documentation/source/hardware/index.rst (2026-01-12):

========
Hardware
========

.. toctree::
   :maxdepth: 3
   :caption: Hardware Documentation:

   materials/index.rst
   abstr
   cstr_overview
   RTD_cell.rst

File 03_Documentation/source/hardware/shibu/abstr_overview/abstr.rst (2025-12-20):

Automated Batch Stirred Tank Reactor (ABSTR)
============================================

OVERVIEW
--------

The automated batch stirred tank reactor (ABSTR) is a software-controlled system that performs cyclic pump operations for continuous photoreactor processing. It sequentially delivers reaction mixture, collects product, washes with solvent, and repeats automatically. Programmable control enables precise timing, adaptable parameters, and reliable, continuous reactor operation.       

complete image

   Figure 1: Complete diagram of the machine

MODULES USED
------------
:doc:`Time controller module <../modules/time_controller>`

time controller module

:doc:`Transit Circuit <../modules/transit_ckt>`

transit circuit module

:doc:`Power Supply <../components/12V_10A_powersupply>`



Connection Instructions
-----------------------
1.Connect the output terminal of the controller to the input terminal of the pump controller to enable software-based actuation.

2.Connect the output terminals of the pump controller individually to each pump for independent operation.

3.Connect the ground of each pump and combine them to form a common ground, then interface this common ground with the power supply ground.

4.Connect the power supply to the pump controller to provide stable operating power.

5.Connect the power supply to the timing controller module to ensure proper timing and sequencing functionality.

6.Refer to the block diagram provided below for a clearer understanding of the overall system architecture and signal flow.

7.After that uplod the arduino code given below after adjusting the parameters required for the timers.

Block Diagram
-------------
block diagram

Arduino code For ABSTR
----------------------

.. code-block:: cpp
   :linenos:

   int A;
   int B;
   int C;
   int D;

   void setup() {
      pinMode(2, OUTPUT);
      pinMode(3, OUTPUT);
      pinMode(4, OUTPUT);
   }

   void loop() {
      A = (10UL * 1UL * 1000UL);
      B = (10UL * 1UL * 1000UL);
      D = (10UL * 1UL * 1000UL);

      digitalWrite(2, HIGH);
      digitalWrite(3, LOW);
      digitalWrite(4, LOW);
      delay(A);

      digitalWrite(2, LOW);
      digitalWrite(3, HIGH);
      delay(B);

      digitalWrite(2, HIGH);
      digitalWrite(3, LOW);
      delay(A);

      digitalWrite(2, LOW);
      digitalWrite(4, HIGH);
      delay(D);

      digitalWrite(4, LOW);
      digitalWrite(7, HIGH);
      delay(60UL * 12UL * 1000UL);

      digitalWrite(7, LOW);
      digitalWrite(LED_BUILTIN, HIGH);
   }

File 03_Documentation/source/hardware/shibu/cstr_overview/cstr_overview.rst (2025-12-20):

Continuous Batch Stirred Tank Reactor (CSTR)
============================================

OVERVIEW
--------
The continuous batch stirred tank reactor (CSTR) is a software-assisted system designed to operate continuously while maintaining controlled flow rates and stable reactor volume. It uses dedicated inlet, outlet, and looping pumps to regulate mass, recirculate reactor effluent, and sustain a falling-film stirring environment. Through predefined flow parameters and dynamic feedback from an integrated weighing scale, the control software modulates pump operation to keep the reactor mass within target limits. Adjustable experimental settings allow the system to be optimized for different reaction conditions, ensuring stable, scalable, and efficient continuous operation.

complete image

   Figure 1: Complete diagram of the machine

MODULES USED
------------

:doc:`Measurement Module<../modules/weigh_scale>`

Measurement Module

:doc:`Power Supply <../components/12V_10A_powersupply>`

power supply module

:doc:`PUMP SPEED CONTROLLER <../modules/pump_controller>`

pump speed controller

:doc:`Transit Circuit <../modules/transit_ckt>`

transit circuit module

:doc:`CSTR OPERATIONAL CKT <../modules/cstr_operational_ckt>`

cstr operational circuit

:doc:`Low Flow Peristaltic Pump <../components/perisstalticpump_lowflow>`

low flow peristaltic pump

:doc:`High Flow Peristaltic Pump <../components/peristalticpump_highflow>`

high flow peristaltic pump

Assembly Instruction
--------------------

1.Connect the Power of the measurement scale with the adapter

2.connect the output of the measurement scale with the input of the cstr operational circuit according to block diagram below

3.connect the power of the cstr operational module.

4.connect the inlet and outlet pump with the cstr operational circuit according to the block diagram below.

5.Connect the ground of all the modules to form a common ground.

6. Refer to the block diagram provided below for a clearer understanding of the overall system architecture and signal flow.

7. Upload the arduino code given below after adjusting the parameters required for the weighing scale and pumps.

Block Diagram
-------------

cstr block diagram

   Figure: Block diagram of CSTR circuit

Arduino Code for CSTR
---------------------

.. code-block:: cpp
   :linenos:

   #include <HX711_ADC.h>
   #include <Wire.h>
   #include <LiquidCrystal_I2C.h> // LiquidCrystal_I2C library

   HX711_ADC LoadCell(4, 5);  // dt pin, sck pin
   LiquidCrystal_I2C lcd(0x27, 16, 2); // LCD HEX address 0x27

   int taree = 6;
   int a = 0;
   float b = 0;
   int inlet = 7;
   int outlet = 8;

   int max = 20.5 // set the maximum weight of the reactant
   int min = 19.5 // set the minimum weight of the reactant

   void setup() {
      pinMode(inlet, OUTPUT);
      pinMode(outlet, OUTPUT);
      pinMode(taree, INPUT_PULLUP);

      LoadCell.begin(); // start connection to HX711
      LoadCell.start(1000); // load cells get 1000ms of time to stabilize

      ///////////////////////////////////////////
      LoadCell.setCalFactor(375); // Calibrate your LOAD CELL with 100g weight,
                                 // and change the value according to readings
      ///////////////////////////////////////////

      // initialize the LCD
      lcd.begin();      // begins connection to the LCD module
      lcd.backlight();  // turns on the backlight
      lcd.setCursor(1, 0); // set cursor to first row
      lcd.print("Digital Scale "); // print out to LCD
      lcd.setCursor(0, 1); // set cursor to first row
      lcd.print(" SHIBU NASKAR "); // print out to LCD
      delay(3000);
      lcd.clear();
   }

   void loop() {
      lcd.setCursor(1, 0); // set cursor to first row
      lcd.print("Digital Scale "); // print out to LCD

      LoadCell.update(); // retrieves data from the load cell
      float i = LoadCell.getData(); // get output value

      if (i < 0) {
         i = i * (-1);
         lcd.setCursor(0, 1);
         lcd.print(" ");
         lcd.setCursor(8, 1);
         lcd.print(" ");
      } else {
         lcd.setCursor(0, 1);
         lcd.print(" ");
         lcd.setCursor(8, 1);
         lcd.print(" ");

         lcd.setCursor(1, 1); // set cursor to second row
         lcd.print(i); // print out the retrieved value to the second row
         lcd.print("g ");
         float z = i / 28.3495;
         lcd.setCursor(9, 1);
         lcd.print(z, 2);
         lcd.print("oz ");

         if (i > 5000) {
               i = 0;
               lcd.setCursor(0, 0); // set cursor to second row
               lcd.print(" Over loaded ");
               delay(200);
         }

         if (i > max) {
               digitalWrite(outlet, HIGH);
               delay(10);
               digitalWrite(inlet, LOW);
               delay(800);
         } else if (i < min) {
               digitalWrite(inlet, HIGH);
               delay(10);
               digitalWrite(outlet, LOW);
               delay(800);
         } else if (i >= min && i <= max) {
               digitalWrite(outlet, HIGH);
               digitalWrite(inlet, HIGH);
               delay(800);
         } else {
               digitalWrite(outlet, LOW);
               digitalWrite(inlet, LOW);
               delay(800);
         }
      }
   }

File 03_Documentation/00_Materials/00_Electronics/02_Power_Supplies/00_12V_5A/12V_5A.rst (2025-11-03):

12V 5A
======
:Manufacturer: LEICKE
:ASIN: B001W3UYLY
:Manufacturer reference: NT03012
:Size: 3 x 11 x 5 cm
:Link: https://www.amazon.de/gp/product/B001W3UYLY/ref=ox_sc_act_title_2?smid=A2Z54WBF904K0X&psc=1

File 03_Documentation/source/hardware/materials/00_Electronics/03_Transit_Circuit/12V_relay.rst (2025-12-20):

12V Relay
=========

:Manufacturer: Songle
:SKU: R233534
:Manufacturer reference: SRD-12VDC-SL-C
:Supplier: robu.in
:Link: https://robu.in/product/1-month-warranty-1027/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

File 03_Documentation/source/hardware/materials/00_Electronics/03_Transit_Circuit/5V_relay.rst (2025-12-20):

5V Relay
========

:Manufacturer: Songle
:SKU: R249407
:Manufacturer reference: SRD-5VDC-SL-A
:Supplier: robu.in
:Link: https://robu.in/product/srd-5vdc-sl-a-ningbo-songle-relay-250vac-5v-15a-1-form-a-1a-spst-no-plugin15-6x19-2mm-power-relays-rohs/

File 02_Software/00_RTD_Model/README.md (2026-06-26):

# Falling Film Loop Photoreactor RTD

## Summary

This subfolder contains the residence time distribution (RTD) analysis of a Falling Film Loop Photoreactor.

## Contents

- `00_Processed_Data/`: Processed and evaluated `.csv` files.
- `01_Figures/`: Plots of the RTD analysis.
- `main.ipynb`: Jupyter Notebook with RTD analysis code.

## Installation

Install the required Python packages using:

```bash
pip install --only-binary :all: -r requirements.txt
```

## Requirements

- Python < 3.12
- All required Python packages are listed in `requirements.txt`

## Models and Equations

To determine the Bodenstein number from the RTD experiments, an axial dispersion model with **closed–closed boundary conditions**[^1] is fitted to the experimental data. The input signal is modeled as an ideal Dirac pulse, since injection time ≪ residence time.

The implementation is based on the `rtdpy` package[^2]. Detailed equations and boundary conditions can be found in the [rtdpy documentation](https://merck.github.io/rtdpy/AxialDispersion_cc.html).

The mean residence time $\bar{\tau}$ is calculated as the first moment of the experimental residence time density function $E_\mathrm{exp}(t)$:

$$
\bar{\tau} = \int_0^\infty t \cdot E_\mathrm{exp}(t) \, dt
$$

## Results

The figures and table below summarize the results of the RTD analysis as a function of external flow rate. The Bodenstein number is reported together with the half-width of its 95 % confidence interval (Bo ± CI) and the coefficient of determination $R^2$ of the fit.

### Mean Residence Time and Bodenstein number

<table>
     <thead>
    <tr>
      <th>Flow Rate (mL min⁻¹)</th>
      <th>Mean Residence Time (s)</th>
      <th>Hydrodynamic Mean Residence Time (s)</th>
      <th>Bodenstein Number (1)</th>
      <th>95 % CI (1)</th>
      <th>R² (1)</th>
    </tr>
  </thead>
  <tbody>
    <tr>
      <td>3.3</td>
      <td>272.02</td>
      <td>363.64</td>
      <td>0.56</td>
      <td>0.01</td>
      <td>0.85</td>
    </tr>
    <tr>
      <td>5.0</td>
      <td>174.05</td>
      <td>240.00</td>
      <td>1.13</td>
      <td>0.03</td>
      <td>0.90</td>
    </tr>
    <tr>
      <td>10.0</td>
      <td>119.29</td>
      <td>120.00</td>
      <td>0.53</td>
      <td>0.02</td>
      <td>0.90</td>
    </tr>
    <tr>
      <td>20.0</td>
      <td>80.91</td>
      <td>60.00</td>
      <td>0.58</td>
      <td>0.02</td>
      <td>0.91</td>
    </tr>
    <tr>
      <td>40.0</td>
      <td>73.21</td>
      <td>30.00</td>
      <td>0.44</td>
      <td>0.02</td>
      <td>0.90</td>
    </tr>
  </tbody>
</table>

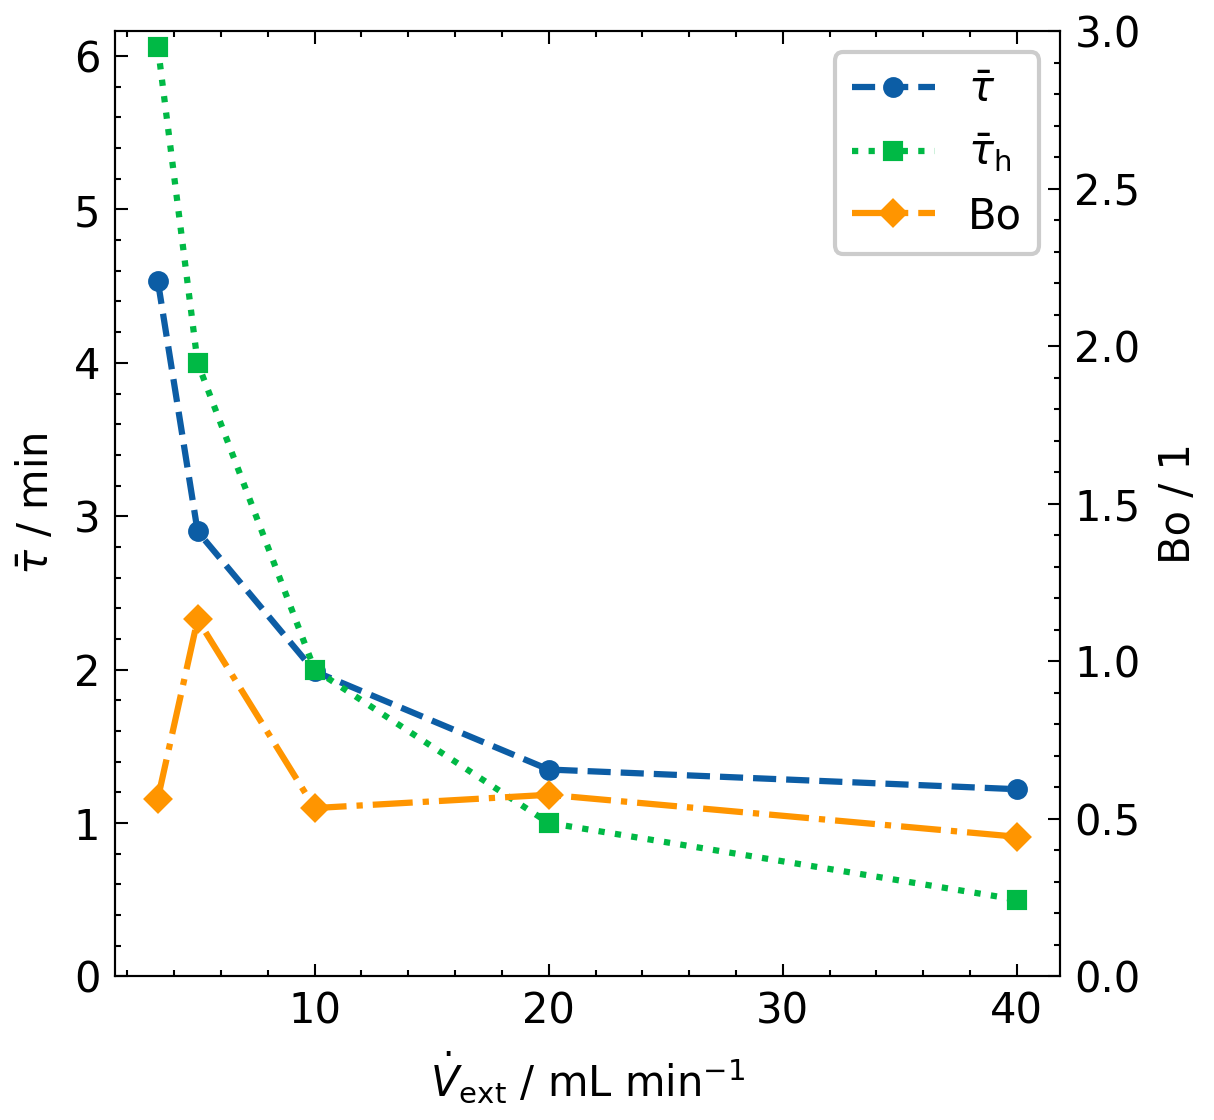
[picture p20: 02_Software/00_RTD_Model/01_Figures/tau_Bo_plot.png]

<br>
<br>

### Comparison of Experimental Data and Simulation

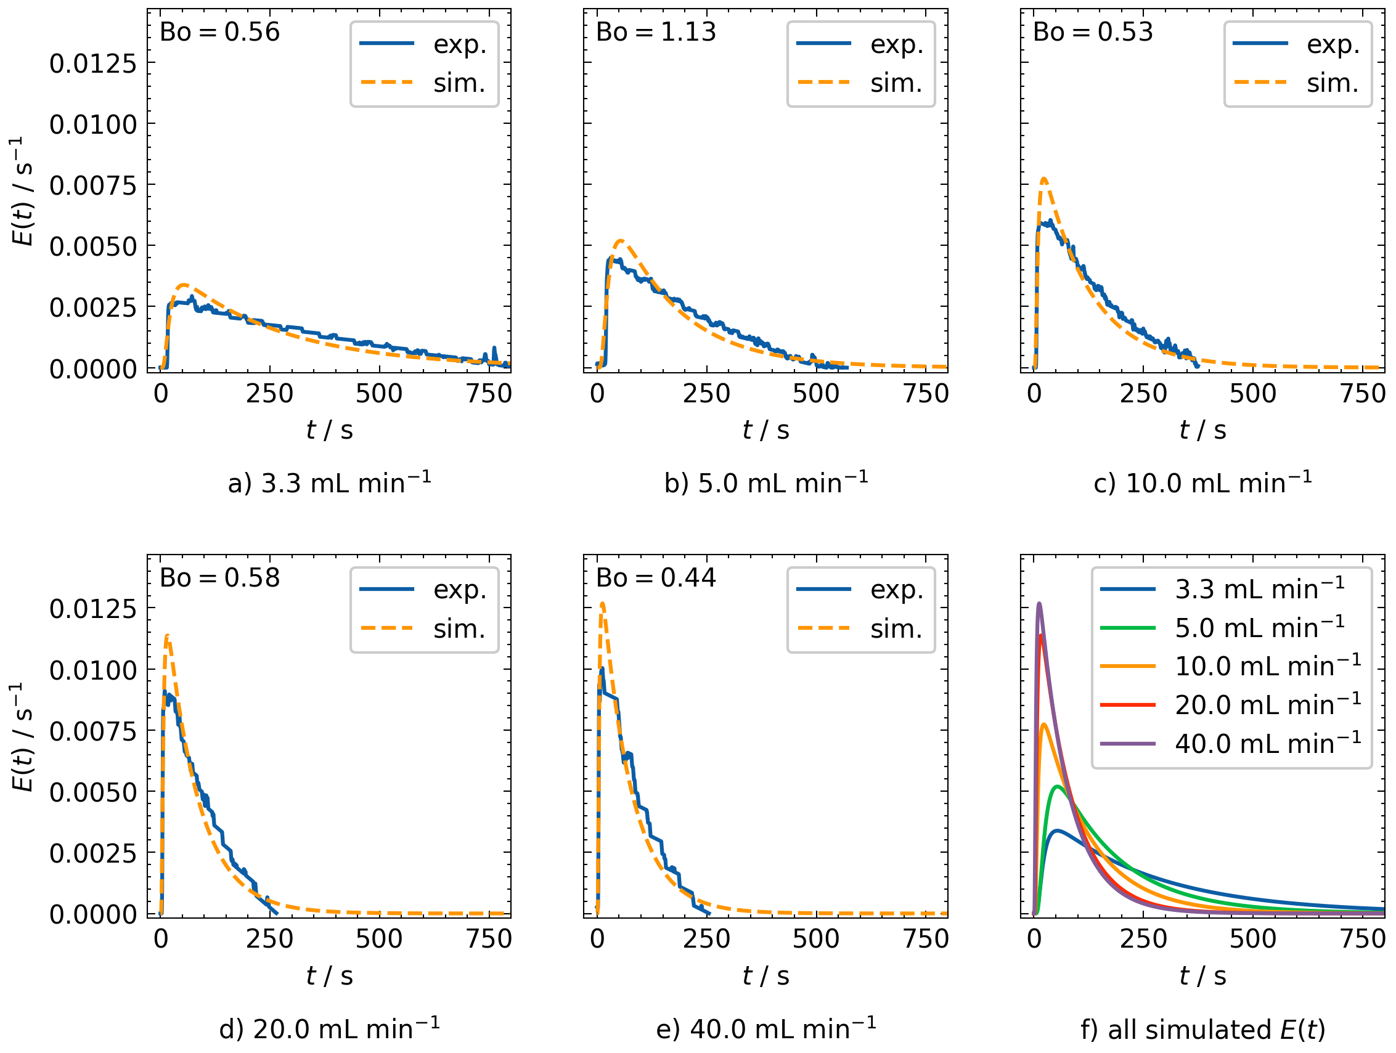
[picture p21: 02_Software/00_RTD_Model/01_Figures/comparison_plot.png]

<br>
<br>

### Simulated RTD Functions at Increasing Flow Rates

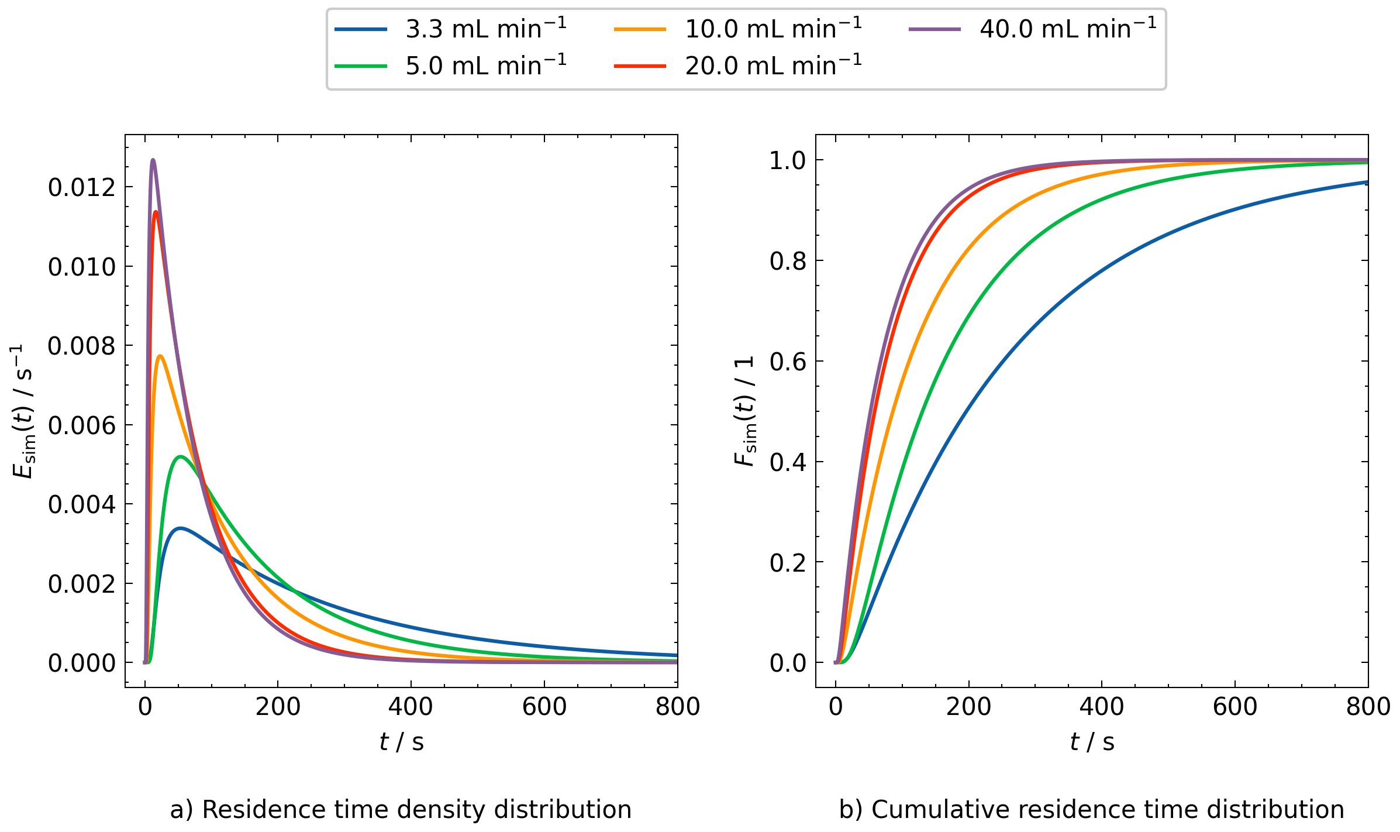
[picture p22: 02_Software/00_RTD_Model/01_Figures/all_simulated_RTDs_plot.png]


## References

[^1]: O. Levenspiel, Chemical reaction engineering. Hauptbd., 3. ed, Wiley, New York Weinheim, 1999.
[^2]: Flamm, M. rtdpy: A python package for residence time distributions. Journal of Open Source Software. , 4(40) , 1621. (2019).

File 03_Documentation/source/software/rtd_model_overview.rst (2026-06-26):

Residence Time Distribution Model Software Overview
===================================================================

Summary
-------

The Residence Time Distribution (RTD) model software is designed to analyze experimental RTD data obtained from the Falling Film Looping Photoreactor (FFLPR). It processes raw data files, fits an axial dispersion model to the experimental data, and calculates key parameters such as the mean residence time and Bodenstein number. It is available here: `RTD Model Software <https://github.com/photonZfeed/FallingFilmLoopingPhotoreactor/tree/main/02_Software/00_RTD_Model>`_.

Contents
--------

- ``00_Processed_Data/``: Processed and evaluated ``.csv`` files.
- ``01_Figures/``: Plots of the RTD analysis.
- ``main.ipynb``: Jupyter Notebook with RTD analysis code.
- ``main.py``: Jupytext mirror of the notebook exposing the analysis functions as an importable module.

Installation
--------------

Install the required Python packages using:

.. code-block:: bash

    pip install --only-binary :all: -r requirements.txt

Requirements
--------------

- Python 3.11
- All required Python packages are listed in ``requirements.txt``.

Models and Equations
----------------------

To determine the Bodenstein number from the RTD experiments, an axial dispersion model with **closed–closed boundary conditions** [1]_ is fitted to the experimental data. The input signal is modeled as an ideal Dirac pulse, since injection time ≪ residence time.

The implementation is based on the ``rtdpy`` package [2]_. Detailed equations and boundary conditions can be found in the rtdpy documentation: https://merck.github.io/rtdpy/AxialDispersion_cc.html

The mean residence time :math:`\bar{\tau}` is calculated as the first moment of the experimental residence time density function :math:`E_{\mathrm{exp}}(t)`:

.. math::

    \bar{\tau} = \int_0^\infty t \cdot E_{\mathrm{exp}}(t) \, dt

The Bodenstein number :math:`\mathrm{Bo}` is obtained by fitting the simulated exit age distribution :math:`E_{\mathrm{sim}}(t)` to the experimental one by nonlinear least squares, minimizing the sum of squared residuals over the experimental time range:

.. math::

    \min_{\mathrm{Bo}} \; \sum_i \left( E_{\mathrm{sim}}(t_i; \bar{\tau}, \mathrm{Bo}) - E_{\mathrm{exp}}(t_i) \right)^2

The goodness of fit is quantified by the coefficient of determination :math:`R^2`, evaluated over the experimental time range. A 95 % confidence interval for the fitted Bodenstein number is estimated from the linearized (Gauss–Newton) covariance of the nonlinear least-squares problem,

.. math::

    \mathrm{Var}(\mathrm{Bo}) = \frac{s^2}{\sum_i \left( \partial E_{\mathrm{sim}}(t_i) / \partial \mathrm{Bo} \right)^2}, \qquad s^2 = \frac{1}{n - 1} \sum_i \left( E_{\mathrm{exp}}(t_i) - E_{\mathrm{sim}}(t_i) \right)^2,

where the parameter sensitivity :math:`\partial E_{\mathrm{sim}} / \partial \mathrm{Bo}` is computed by finite differences and the reported half-width is :math:`1.96\,\sqrt{\mathrm{Var}(\mathrm{Bo})}`.

Results
--------

The figures and table below summarize the results of the RTD analysis as a function of external flow rate.

Mean Residence Time and Bodenstein number
------------------------------------------

The Bodenstein number is reported with the half-width of its 95 % confidence interval (Bo ± CI).

.. list-table::
   :header-rows: 1
   :widths: 16 18 24 16 10 8

   * - Flow Rate (mL min⁻¹)
     - Mean Residence Time (s)
     - Hydrodynamic Mean Residence Time (s)
     - Bodenstein Number (1)
     - 95 % CI (1)
     - R² (1)
   * - 3.3
     - 272.02
     - 363.64
     - 0.56
     - 0.01
     - 0.85
   * - 5.0
     - 174.05
     - 240.00
     - 1.13
     - 0.03
     - 0.90
   * - 10.0
     - 119.29
     - 120.00
     - 0.53
     - 0.02
     - 0.90
   * - 20.0
     - 80.91
     - 60.00
     - 0.58
     - 0.02
     - 0.91
   * - 40.0
     - 73.21
     - 30.00
     - 0.44
     - 0.02
     - 0.90



Comparison of Experimental Data and Simulation
-----------------------------------------------

Comparison of experimental data and simulation

Simulated RTD Functions at Increasing Flow Rates
-------------------------------------------------

Simulated RTD functions at increasing flow rates

References
-----------

.. [1] O. Levenspiel, Chemical reaction engineering. Hauptbd., 3. ed, Wiley, New York Weinheim, 1999.
.. [2] Flamm, M. rtdpy: A python package for residence time distributions. Journal of Open Source Software, 4(40), 1621 (2019).

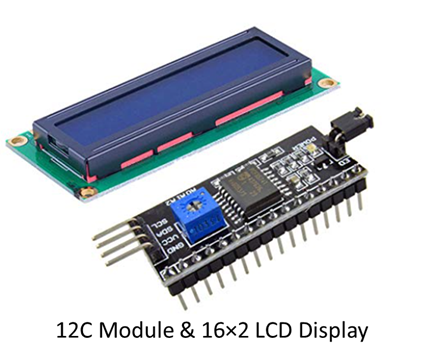
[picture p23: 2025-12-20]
03_Documentation/source/_static/figures/i2cmodule.png

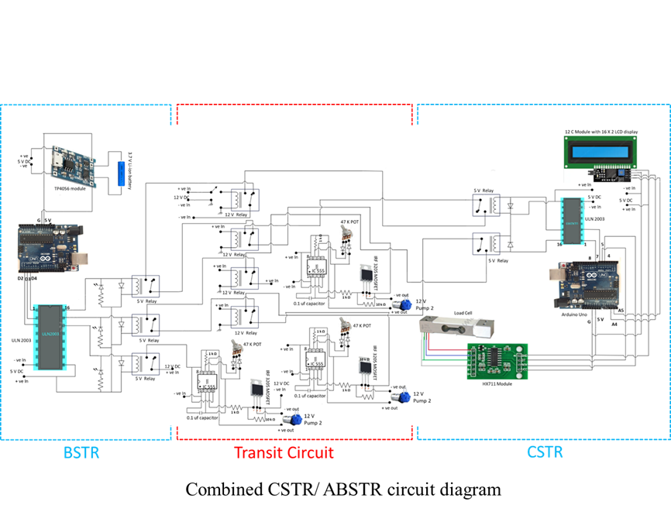
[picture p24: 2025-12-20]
03_Documentation/source/_static/figures/combined_circuit.png

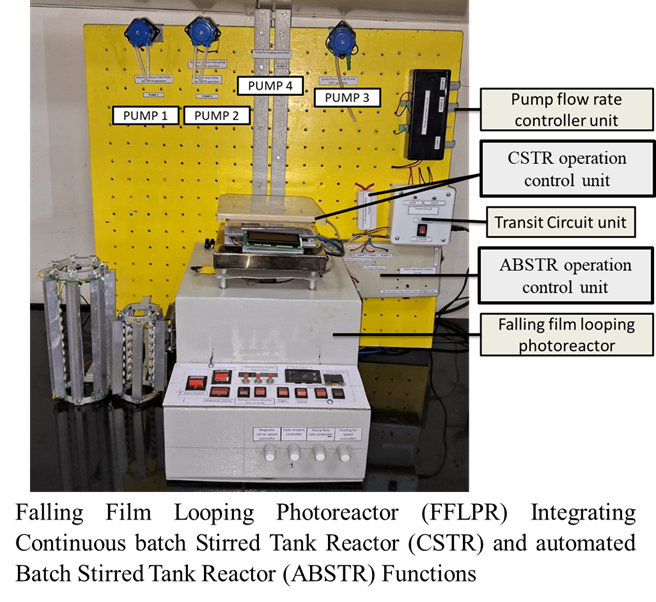
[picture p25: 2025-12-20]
03_Documentation/source/_static/figures/combined_reactor.png

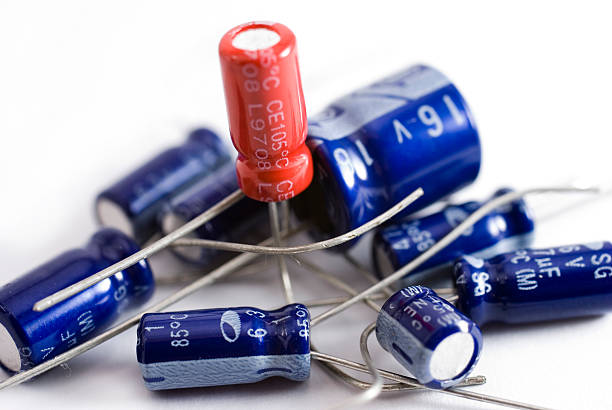
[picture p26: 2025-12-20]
03_Documentation/source/_static/figures/capacitor.jpg

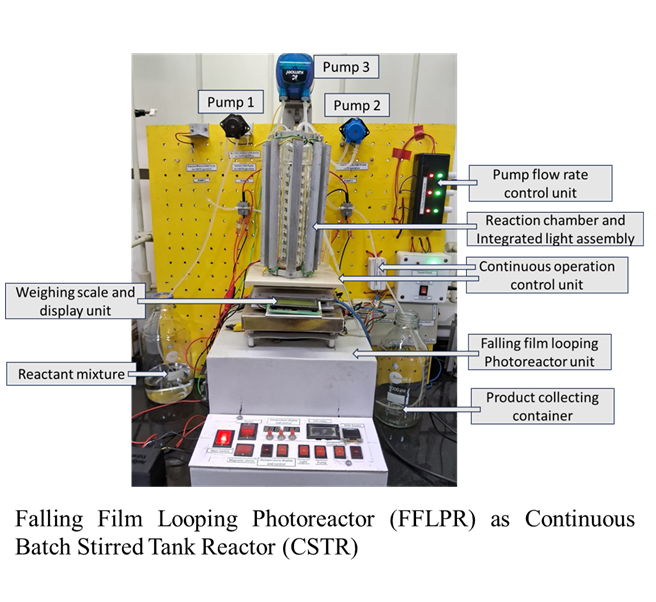
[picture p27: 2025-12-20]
03_Documentation/source/_static/figures/cstr.png

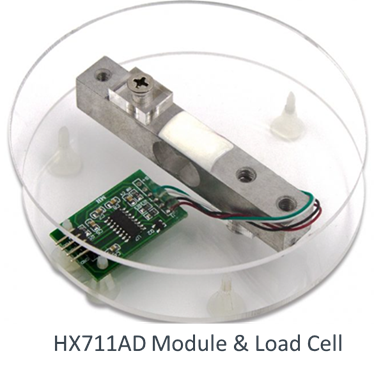
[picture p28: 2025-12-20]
03_Documentation/source/_static/figures/hx711module.png

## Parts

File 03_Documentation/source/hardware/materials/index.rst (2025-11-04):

==========
Materials
==========

.. toctree::
   :maxdepth: 1
   :caption: Overview

   ./00_Electronics/index
   ./01_Accessories/index

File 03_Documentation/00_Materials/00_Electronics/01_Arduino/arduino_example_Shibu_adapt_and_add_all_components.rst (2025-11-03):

:Manufacturer: Arduino S.r.l
:SKU / Barcode: ABX00162 / 7630049205673
:Manufacturer reference: Arduino UNO Q
:Supplier: Arduino S.r.l
:Link: https://store.arduino.cc/products/uno-q
:Link data sheet: https://docs.arduino.cc/resources/datasheets/ABX00162-ABX00173-datasheet.pdf

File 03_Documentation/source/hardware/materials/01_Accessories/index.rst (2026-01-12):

=================
Accessories
=================

.. toctree::
   :maxdepth: 1
   :caption: Overview
   :glob:

   ../../materials/01_Accessories/*

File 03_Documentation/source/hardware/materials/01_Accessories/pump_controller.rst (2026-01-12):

CSTR OPERATIONAL MODULES
========================

block diagram of CSTR

   Figure: Block diagram of CSTR circuit

OVERVIEW
========

The continuous operation control unit is a software-driven system engineered to maintain steady, predetermined inlet and outlet flow rates through precision-controlled pump operations. The flow rates are established based on experimentally determined residence times and are programmed prior to initiating the continuous reaction sequence. The system comprises two primary pumps for inlet and outlet flow, as well as an auxiliary looping pump for internal circulation.

Circuit Diagram
===============

circuit diagram of CSTR

   Figure: Circuit diagram of CSTR circuit

Components Used
---------------

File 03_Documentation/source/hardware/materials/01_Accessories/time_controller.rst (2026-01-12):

Time controller
---------------

The time controller device governs the entire operation by triggering each pump according to predefined timings and flow durations. At the start of the cycle, the controller activates Pump 1 for a set time to introduce the required volume of reaction mixture into the reactor. After the reaction time elapses, the controller switches to Pump 3, which runs for a specific duration to remove the processed product from the reactor. Once product removal is completed, the controller enables Pump 2 to supply a calculated amount of solvent for washing. Following solvent introduction, Pump 3 is again activated by the controller to expel the solvent and any residual materials. This time-based switching sequence forms one complete operating cycle, and the controller continues to loop through these pump operations automatically until the system is stopped.

time controller block diagram

Circuit Diagram
---------------
The circuit diagram of the time controller module illustrates the electronic components and their interconnections that facilitate the timing and control functions. It includes microcontrollers, relays, resistors, capacitors, and other essential elements that work together to manage the pump operations based on the programmed timing sequences.

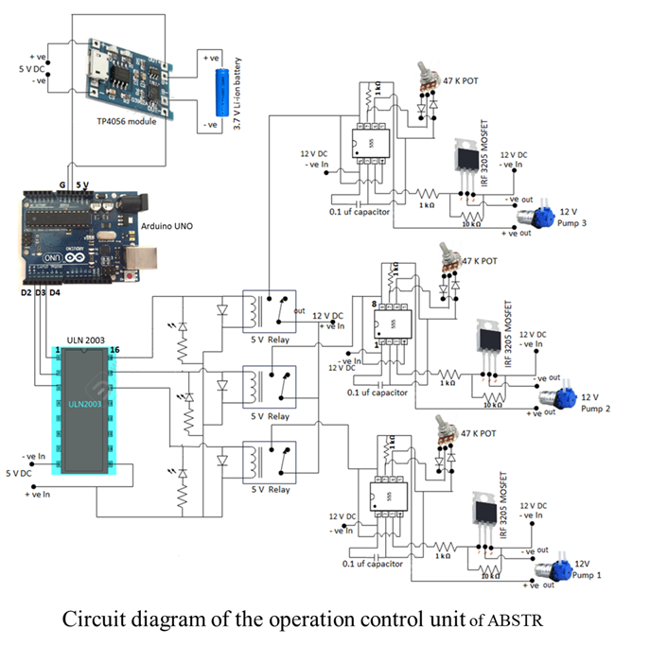
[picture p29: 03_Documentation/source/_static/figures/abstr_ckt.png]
time controller circuit diagram


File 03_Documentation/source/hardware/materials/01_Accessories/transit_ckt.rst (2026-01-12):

TRANSIT Circuit 
================

OVERVIEW
--------
The transit circuit functions as a switching interface that allows the system to choose between ABSTR and CSTR operation. It uses a relay and two selector switches to route control signals to the desired reactor setup. When ABSTR is selected, the relay directs the controller output to the batch operation modules; when switched to CSTR, it redirects signals to the continuous reactor hardware. This arrangement ensures safe, isolated, and convenient switching between modes without changing wiring.

circuit diagram of CSTR

   Figure: CSTR circuit

Components Used:
----------------

:doc:`Relay <../../materials/00_Electronics/05_Small_Parts_CSTR/relay>`

Switch

3mm Leds

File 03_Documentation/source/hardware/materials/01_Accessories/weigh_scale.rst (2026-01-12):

weight scale
=============

overview
--------

A weight scale is used to measure the weight of the reactant.

circuit diagram
--------------- 

circuit diagram of CSTR

   Figure: Circuit diagram of CSTR circuit  

components used
---------------
:doc:`ULN2003 <../../materials/00_Electronics/05_Small_Parts_CSTR/ULN2003_IC>`

:doc:`relay <../../materials/00_Electronics/05_Small_Parts_CSTR/relay>`

:doc:`HX711 <../../materials/00_Electronics/05_Small_Parts_CSTR/HX711_loadcell>`
:doc:`Arduino <../../materials/00_Electronics/01_Arduino/Arduino_Uno_Rev3_A000066>`

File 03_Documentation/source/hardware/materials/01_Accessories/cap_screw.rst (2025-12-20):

Cap Screws
==========

:Manufacturer: arihant.Del
:Supplier: Amazon
:Link: https://www.amazon.in/Screws-Different-Sizes-Stainless-Industry/dp/B08G8V1V1P

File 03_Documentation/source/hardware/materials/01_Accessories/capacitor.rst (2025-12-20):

capacitor
=========

:Manufacturer: AVS COMPONENTS
:Dissipation factor: 2.5%
:Temperature range: -50C to +85C
:Voltage: 50v
:Supplier: Amazon
:Link: https:  https://www.amazon.in/AVS-COMPONENTS-Ceramic-Capacitor-50pcs/dp/B08THNHHHX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

Value 0.1uf (104)

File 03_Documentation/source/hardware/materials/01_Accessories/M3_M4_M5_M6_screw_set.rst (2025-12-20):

M3,M4,M5 & M6 Screw Set
=======================

:Manufacturer: Epitome M.
:Supplier: Amazon
:Link: https://www.amazon.in/Epi-Torque-Epic-Torque-Doityourself-Assortment/dp/B08F4K55T2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

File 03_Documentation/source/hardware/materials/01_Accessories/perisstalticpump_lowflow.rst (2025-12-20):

Low flow peristaltic pump
=========================

:Manufacturer: Kamoer
:SKU: 857297
:Supplier: robu.in
:Link: https://robu.in/product/kamoer-12v-0-25a-10ml-min-silicone-tube-liquid-pump/

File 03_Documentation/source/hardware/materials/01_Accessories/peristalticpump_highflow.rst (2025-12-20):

High flow peristaltic pump
==========================

:Manufacturer: Kamoer
:SKU: 1005095
:Supplier: robu.in
:Link: https://robu.in/product/kamoer-12v-540ml-min-silicon-tube-brush-motor-3-rollers-liquid-peristaltic-pump/

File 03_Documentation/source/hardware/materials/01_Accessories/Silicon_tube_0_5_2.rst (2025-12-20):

Silicon tube (ID & OD 0.5mm & 2 mm respectively)
================================================

:Manufacturer: Kamoer
:SKU: 1770405
:Supplier: robu.in
:Link: https://robu.in/product/10meters-transparent-silicone-tube-flexible-rubber-hose-drink-water-pipe-food-grade-connector-id-0-5mm-x-2mm-od/

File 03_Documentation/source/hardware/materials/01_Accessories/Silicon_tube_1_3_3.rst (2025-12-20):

Silicon tube (ID & OD 1.3 mm & 3 mm respectively)
=================================================

:Manufacturer: Kamoer
:SKU: 1275343
:Supplier: robu.in
:Link: https://robu.in/product/silicon-tube-1-x-3-3mm/

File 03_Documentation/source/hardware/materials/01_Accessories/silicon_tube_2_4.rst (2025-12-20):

Silicon tube (ID & OD 2 mm & 4 mm respectively)
===============================================

:Manufacturer: Kamoer
:Supplier: amazon
:Link: https://www.amazon.in/Silicone-Tubing-Kamoer-peristaltic-transfer/dp/B092V8PR3Y?th=1

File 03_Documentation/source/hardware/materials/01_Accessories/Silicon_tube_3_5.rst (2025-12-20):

Silicon tube (ID & OD 3 mm & 5 mm respectively)
===============================================

:Manufacturer: Kamoer
:SKU: 1275339
:Supplier: robu.in
:Link: https://robu.in/product/kamoer-silicone-tube-id-3mm-od-5mm-l-100cm-for-peristaltic-pumps/

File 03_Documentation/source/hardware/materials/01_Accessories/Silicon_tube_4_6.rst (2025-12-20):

Silicon tube (ID & OD 4 mm & 6 mm respectively)
===============================================

:Manufacturer: Kamoer
:Supplier: amazon
:Link: https://www.amazon.in/Silicone-Tubing-Kamoer-peristaltic-transfer/dp/B092V7GMLR?th=1

ASIN	‎B092V7GMLR

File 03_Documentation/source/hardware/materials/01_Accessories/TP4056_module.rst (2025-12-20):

TP4056 module
=============

:Supplier: robu.in
:SKU: 835842
:Input interface: Type C
:Current Protection: Yes
:Charging mode: Linear charging.
:Current: 1A adjustable.
:Charge precision: 1.5%.
:Input voltage: 4.5V-5.5V.
:Full charge voltage: 4.2V.
:Link: https://robu.in/product/tp4056-1a-li-ion-lithium-battery-charging-module-with-current-protection-type-c/

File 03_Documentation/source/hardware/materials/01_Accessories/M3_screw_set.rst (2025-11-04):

.. _m3_hex_screw_set:

M3 hex screw set
===================================

:Manufacturer: Hotott
:Name: 1110-piece M3 hex screw set
:Supplier: Amazon
:ASIN: B08F4SVS2Y
:Link: https://www.amazon.de/-/en/M3-Stainless-Hexagon-Washers-Storage/dp/B08F4SVS2Y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

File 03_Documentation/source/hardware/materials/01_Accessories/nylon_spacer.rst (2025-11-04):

.. _nylon_spacer:
 
Nylon Spacer M3 - 10mm
=======================

:Manufacturer: DJJRX
:AISN: B09C21MS45
:Supplier: Amazon
:Link: https://www.amazon.de/Sechskantschrauben-Schaltungs-Abstandshalter-M%C3%A4nnlichen-Zylinderabstandshalter/dp/B09C21MS45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

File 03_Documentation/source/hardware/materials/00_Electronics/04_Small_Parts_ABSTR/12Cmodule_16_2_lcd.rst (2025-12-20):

12C module & 16*2 LCD display
=============================

:Manufacturer: Easy electronics
:Module dimension: 80mm x 36mm x 15mm
:Viewing area size: 64.5mm x 16mm
:Supplier: Amazon
:Link: https://www.amazon.in/Easy-Electronics-16x2-Module-Arduino/dp/B07GC15X91

Displays 2-lines x 16-characters

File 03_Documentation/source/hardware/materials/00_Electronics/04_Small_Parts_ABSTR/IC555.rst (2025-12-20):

IC 555
======

:Manufacturer: EnGeniusLab
:Manufacturer reference: 555 Timer IC DIP-8 Package
:Supplier: Amazon
:Link: https://www.amazon.in/Embeddinator-Timer-DIP-8-Package-Pack/dp/B0B61B1L5T

Supply Voltage ranges from 5V to 15V
Output Current 200mA

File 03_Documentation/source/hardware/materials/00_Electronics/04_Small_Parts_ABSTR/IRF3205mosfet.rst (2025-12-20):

IRF3205 mosfet
==============

:Manufacturer: Generic
:Manufacturer reference: IRF3205 IRF 3205 Power MOSFET 55V 110A TO-220 NEW
:Supplier: Amazon
:Link: https://www.amazon.in/Generic-10PCS-IRF3205-Power-MOSFET/dp/B071CTZVH1

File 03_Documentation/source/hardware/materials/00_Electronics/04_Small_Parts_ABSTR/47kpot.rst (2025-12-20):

47K potentiometer
=================

:Manufacturer: iBAT Solutions
:Manufacturer reference: 47K OHM potentiometer Rotary pot volume controller
:Supplier: Amazon
:Link: https://www.amazon.in/47K-potentiometer-Rotary-controller-Pack/dp/B0CQCTFQ9W

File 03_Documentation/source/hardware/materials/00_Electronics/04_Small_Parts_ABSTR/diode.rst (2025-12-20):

Diod
====

:Manufacturer: Tayal electronics
:Supplier: Amazon
:Link: https:  https://www.amazon.in/GENUINE-IN4007-RECTIFIER-DIODE-100PCS/dp/B07B8Q5BFW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

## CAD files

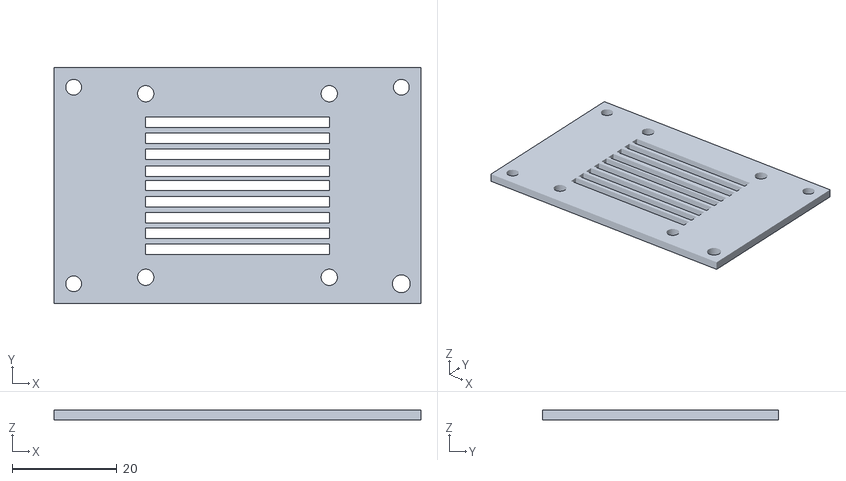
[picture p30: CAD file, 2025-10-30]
03_Documentation/source/_static/cad/base_plate.stl
70.0 x 45.0 x 2.00

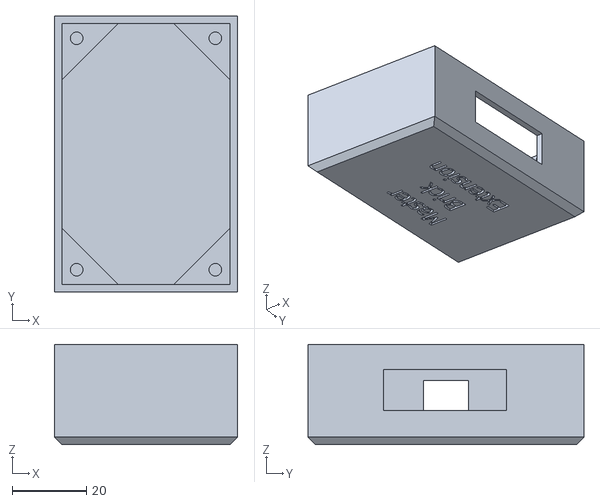
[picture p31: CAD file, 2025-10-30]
03_Documentation/source/_static/cad/case_master_extension.stl
49.4 x 74.4 x 27.0

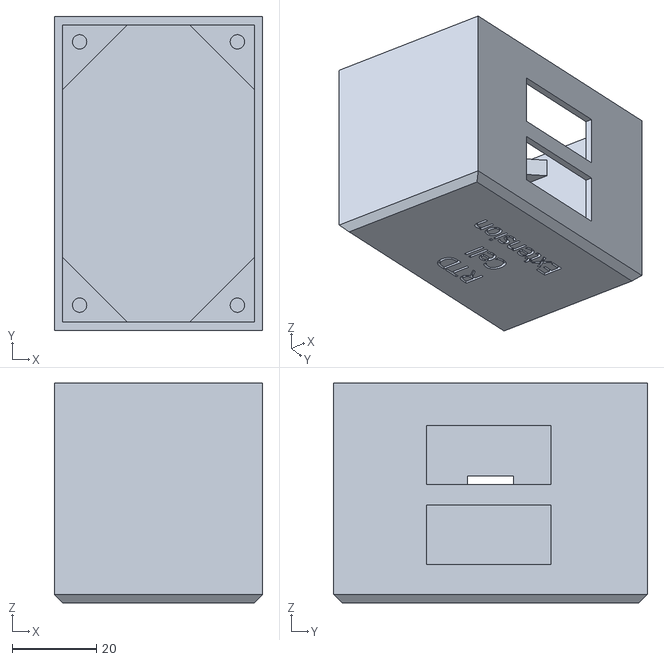
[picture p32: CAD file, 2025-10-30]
03_Documentation/source/_static/cad/case_RTD_cell_extension.stl
49.4 x 74.4 x 52.0

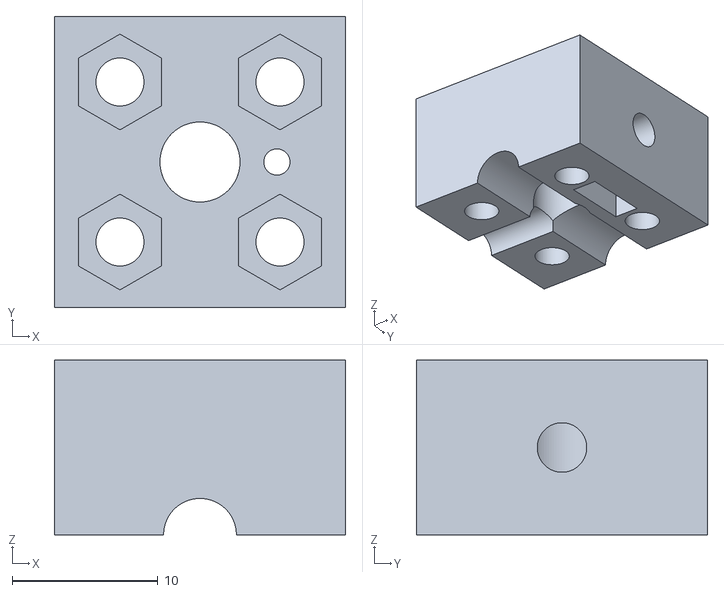
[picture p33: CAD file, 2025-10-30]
03_Documentation/source/_static/cad/RTD_cell_top_3mm_tubing.stl
20.0 x 20.0 x 12.0

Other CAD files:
03_Documentation/source/_static/cad/RTD_cell_top_2mm_tubing.stl
03_Documentation/source/_static/cad/RTD_cell_bottom_3mm_tubing.stl
03_Documentation/source/_static/cad/RTD_cell_bottom_1mm_tubing.stl
03_Documentation/source/_static/cad/RTD_cell_bottom_2mm_tubing.stl
03_Documentation/source/_static/cad/RTD_cell_top_1mm_tubing.stl
03_Documentation/source/_static/cad/RTD_cell_bottom_1mm_tubing.ipt
03_Documentation/source/_static/cad/RTD_cell_bottom_2mm_tubing.ipt
03_Documentation/source/_static/cad/RTD_cell_bottom_3mm_tubing.ipt
03_Documentation/source/_static/cad/RTD_cell_top_1mm_tubing.ipt
03_Documentation/source/_static/cad/RTD_cell_top_2mm_tubing.ipt
03_Documentation/source/_static/cad/RTD_cell_top_3mm_tubing.ipt

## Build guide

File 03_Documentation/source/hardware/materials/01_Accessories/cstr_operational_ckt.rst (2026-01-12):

CSTR operational circuit
========================

circuit diagram of CSTR

working procedure
-----------------

The continuous operation control unit is a software-driven system engineered to maintain steady, predetermined inlet and outlet flow rates through precision-controlled pump operations. The flow rates are established based on experimentally determined residence times and are programmed prior to initiating the continuous reaction sequence.

Circuit Diagram
---------------

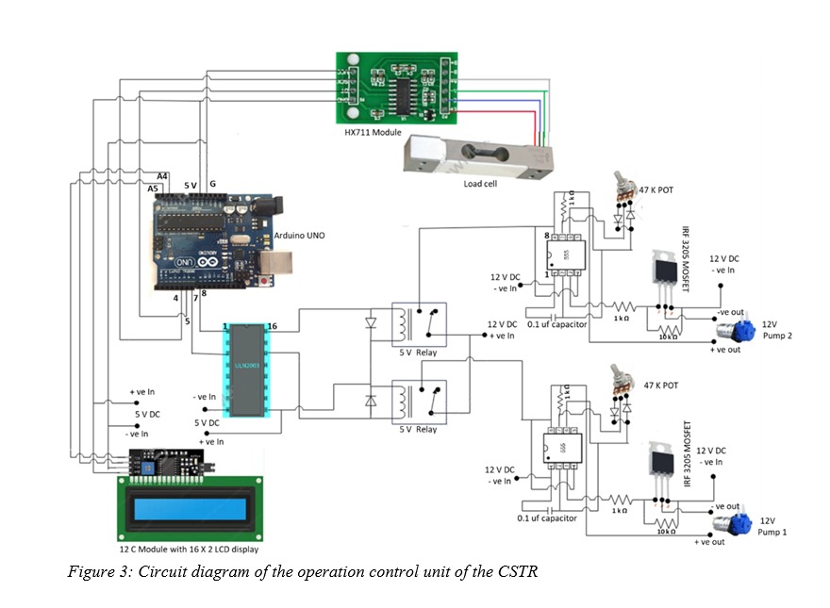
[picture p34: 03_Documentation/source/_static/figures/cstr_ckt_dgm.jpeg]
circuit diagram of CSTR


   Figure: Circuit diagram of CSTR circuit

components Used
---------------

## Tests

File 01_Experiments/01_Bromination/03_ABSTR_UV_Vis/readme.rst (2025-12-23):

UV-Visible Spectrophotometric Data
==================================

This directory contains UV-Visible spectrophotometric data collected for **pure reference compounds** used in the study. The data serve as baseline spectra for comparison in subsequent reaction and mixture analyses.
This directory also contains UV-Visible spectrophotometric data for the time-dependent reaction monitoring at various reactant concentrations (500 mM, 815 mM)

Folder structure Description:
~~~~~~~~~~~~~~~~~~~~~~~~~~~~~

500 mM :
~~~~~~~~

This folder contains UV-Visible spectrophotometric data for the time-dependent reaction monitoring at a reactant concentration of 500 mM.

File naming convention:
~~~~~~~~~~~~~~~~~~~~~~~

- 1.0.txt → Spectrum recorded **0 minutes** after the reaction started
- 1.1.txt → Spectrum recorded **2 minutes** after the reaction started
- 1.2.txt → Spectrum recorded **4 minutes** after the reaction started
- and so on

815 mM scale :
~~~~~~~~~~~~~~

This folder contains UV-Visible spectrophotometric data for the time-dependent reaction monitoring at a reactant concentration of 815 mM.

File naming convention:
~~~~~~~~~~~~~~~~~~~~~~~

- 1.txt → Spectrum recorded **2 minutes** after the reaction started
- 2.txt → Spectrum recorded **4 minutes** after the reaction started
- 4.txt → Spectrum recorded **6 minutes** after the reaction started
and so on

BB and Toluene:
~~~~~~~~~~~~~~~

This folder contains UV-Visible spectrophotometric data collected for **pure reference compounds** used in the study (Benzyl bromide and Toluene).
benzyl_bromide.txt
This file contains the raw UV-Visible **spectrophotometric data** recorded for **pure benzyl bromide**.

toluene.txt
~~~~~~~~~~~

This file contains the **raw UV-Visible spectrophotometric data** recorded for pure toluene.

Notes
~~~~~

- All measurements were performed using a UV-Visible spectrophotometer.
- Experimental parameters (path length, wavelength range, and scan rate) were kept constant for both measurements unless stated otherwise.

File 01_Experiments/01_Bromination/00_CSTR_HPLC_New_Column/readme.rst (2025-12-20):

HPLC Data After Column Replacement
==================================

This directory contains HPLC chromatogram data collected after replacing the HPLC Column. The data are organized based on experimental
conditions, external flow rates, and calibration measurements.

Each subfolder represents a specific experimental configuration, and the PDF
files within the folders correspond to time-resolved HPLC readings.

Folder Overview
---------------

EXP-3: 10 mL·min⁻¹ External Flow Rate
~~~~~~~~~~~~~~~~~~~~~~~~~~~~~~~~~~~~~
This folder contains HPLC chromatograms recorded when the experiment was
performed at an external flow rate of **10 mL·min⁻¹**.

Each PDF file represents the reaction procress after a specific
reaction time.

**File naming convention:**

- ``1.pdf``  → HPLC Data corresponds to the reaction progress after **1 minute** of reaction  
- ``2.pdf``  → HPLC Data corresponds to the reaction progress after **2 minutes** of reaction  
- ``3.pdf``  → HPLC Data corresponds to the reaction progress after **3 minutes** of reaction  
- *and so on*

---

EXP-4: 20 mL·min⁻¹ External Flow Rate
~~~~~~~~~~~~~~~~~~~~~~~~~~~~~~~~~~~~~
This folder contains HPLC data obtained at an external flow rate of
**20 mL·min⁻¹**.

- The experimental procedure and sampling method are identical to EXP-3.
- The file-naming strategy follows the same reaction-time-based convention.

---

EXP-5: 40 mL·min⁻¹ External Flow Rate
~~~~~~~~~~~~~~~~~~~~~~~~~~~~~~~~~~~~~
This folder contains HPLC chromatograms collected at a higher external flow rate
of **40 mL·min⁻¹**.

- The experimental procedure and sampling method are identical to EXP-3.
- The file-naming strategy follows the same reaction-time-based convention.

---

Scale-Up
~~~~~~~~
This folder contains HPLC data **of the large scale experiment**.

- Although the reactor scale differs from laboratory experiments, the sampling
  method and file-naming strategy remain unchanged.
- File names represent the reaction progress time in minutes.

---

Std. Graph (Standard Calibration Data)
~~~~~~~~~~~~~~~~~~~~~~~~~~~~~~~~~~~~~~
This folder contains HPLC standard chromatograms used for calibration curve and equation.

- Each PDF corresponds to a standard solution with a known concentration (µg·mL⁻¹) and their corresponding peek area.
  
- File names corresponds to the increasing order of the concentration of pure benzyl bromide starting from 1.25 µg·mL⁻¹ upto 320 µg·mL⁻¹ following a gp series with general mean of 2

**Examples:**

- ``BB1.pdf``, ``BB2.pdf``, ``BB3.pdf`` → Standard calibration runs  
- ``BLANK.pdf`` → Blank solvent run (zero concentration reference)

These standard graphs are used to generate calibration curves for converting
HPLC peak areas into concentration values.

Notes
-----
- All data were recorded after replacing the HPLC column.
- Experimental conditions other than flow rate were kept consistent unless
  stated otherwise.

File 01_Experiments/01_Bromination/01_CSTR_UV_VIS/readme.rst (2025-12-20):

CSTR UV–Visible Spectrometer Data
=================================

This directory contains UV–Visible spectrometer data collected during the
reaction under different external flow-rate conditions. The data are organized
based on the flow rate at which the experiment was performed.

Each subfolder corresponds to a specific flow rate, and the files within each
folder represent time-resolved UV–Vis measurements collected after the reaction
started.

Folder Structure and Description
--------------------------------

3 mL·min⁻¹
~~~~~~~~~~
This folder contains UV–Visible spectrometer data recorded when the reaction was
performed at an external flow rate of **3 mL·min⁻¹**.

Each data file corresponds to a UV–Vis spectrum collected after a specific
reaction time.

**File naming convention:**

- ``t=2.txt`` → Spectrum recorded **2 minutes** after the reaction started  
- ``t=3.txt`` → Spectrum recorded **3 minutes** after the reaction started  
- ``t=4.txt`` → Spectrum recorded **4 minutes** after the reaction started  
- *and so on*

---

5 mL·min⁻¹
~~~~~~~~~~
This folder contains UV–Visible spectrometer data recorded when the reaction was
performed at an external flow rate of **5 mL·min⁻¹**.

- The experimental procedure and data collection method are identical to those
  used at 3 mL·min⁻¹.
- The file-naming strategy follows the same time-based convention.

**File naming convention:**

- ``t=2.txt`` → Spectrum recorded after **2 minutes**  
- ``t=3.txt`` → Spectrum recorded after **3 minutes**  
- ``t=4.txt`` → Spectrum recorded after **4 minutes**  

---

Notes
-----
- All measurements were recorded using a UV–Visible spectrometer.
- Experimental conditions other than flow rate were kept constant unless stated
  otherwise.

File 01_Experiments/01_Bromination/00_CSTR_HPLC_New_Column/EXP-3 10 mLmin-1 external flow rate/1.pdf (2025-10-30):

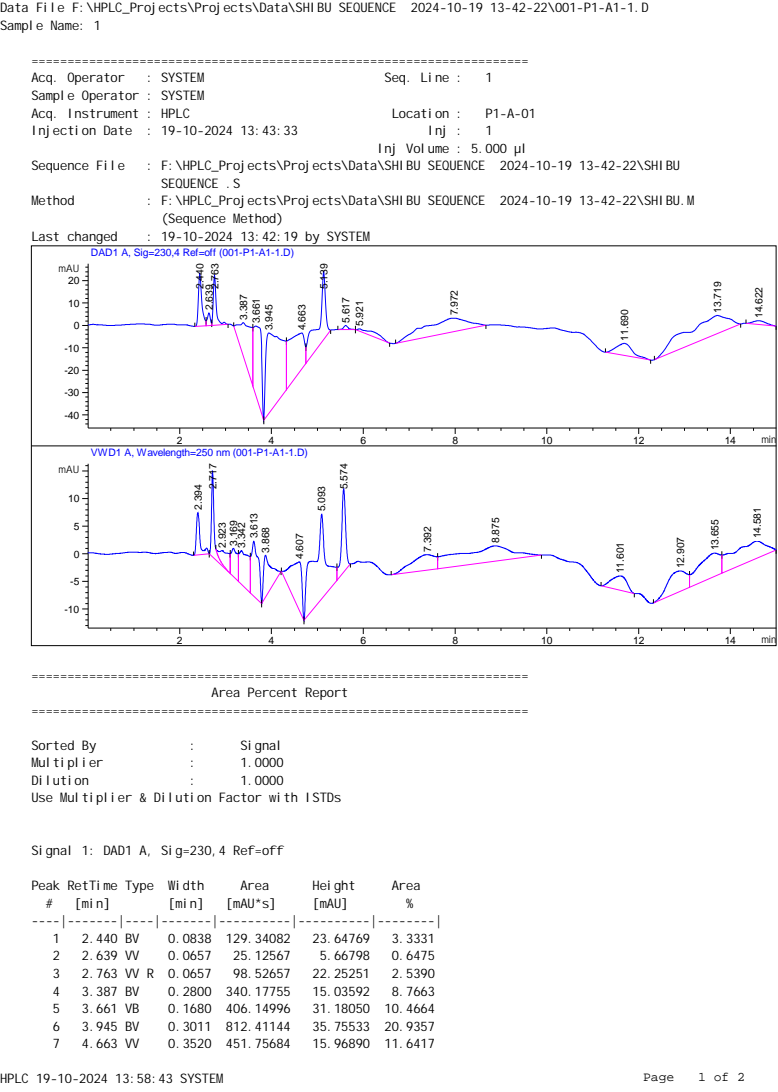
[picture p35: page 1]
Acq. Operator; : SYSTEM; Seq. Line :; Acq. Instrument : HPLC; Location :; Injection Date : 19-10-2024 13:43:33; Inj :; Sequence File; : F:\HPLC_Projects\Projects\Data\SHIBU SEQUENCE 2024-10-19 13-42-22\SHIBU; SEQUENCE .S; Method; : F:\HPLC_Projects\Projects\Data\SHIBU SEQUENCE 2024-10-19 13-42-22\SHIBU.M; (Sequence Method); Last changed; : 19-10-2024 13:42:19 by SYSTEM; min; mAU; VWD1 A, Wavelength=250 nm (001-P1-A1-1.D); Sorted By; Signal; Multiplier; Dilution; Peak RetTime Type Width; Area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

Data File F:\HPLC_Projects\Projects\Data\SHIBU SEQUENCE 2024-10-19 13-42-22\001-P1-A1-1.D
Sample Name: 1

Sample Operator : SYSTEM

Inj Volume : 5.000 µl

DAD1 A, Sig=230,4 Ref=off (001-P1-A1-1.D)

Area Percent Report

Use Multiplier & Dilution Factor with ISTDs

Signal 1: DAD1 A, Sig=230,4 Ref=off

Peak RetTime Type Width | Area | Height | Area
# | [min] | [min] | [mAU*s] | [mAU] | %

8 | 5.139 VB | 0.1568 358.51563 | 30.58200 | 9.2389
9 | 5.617 BB | 0.1051 | 13.07047 | 1.83538 | 0.3368
10 | 5.921 BB | 0.6121 | 56.21395 | 1.10022 | 1.4486
11 | 7.972 BB | 0.8420 429.54813 | 6.00861 11.0694
12 11.690 BB | 0.3409 130.76859 | 5.35430 | 3.3699
13 13.719 BB | 0.9017 593.59528 | 8.03708 15.2968
14 14.622 BBA | 0.2595 | 35.31475 | 1.77985 | 0.9101
Totals : | 3880.51563 204.20627

Signal 2: VWD1 A, Wavelength=250 nm

Peak RetTime Type Width | Area | Height | Area
# | [min] | [min] | [mAU*s] | [mAU] | %

1 | 2.394 BV R 0.0879 | 43.09026 | 7.63308 | 2.3139
2 | 2.717 BV R 0.0624 | 65.87991 | 15.55501 | 3.5377
3 | 2.923 VV E 0.2128 | 40.46814 | 2.37473 | 2.1731
4 | 3.169 VV | 0.1280 | 49.67447 | 5.12990 | 2.6675
5 | 3.342 VV | 0.1934 | 93.37708 | 6.07271 | 5.0143
6 | 3.613 VB | 0.1404 106.14330 | 9.95344 | 5.6998
7 | 3.868 BB | 0.1550 | 86.38090 | 7.69086 | 4.6386
8 | 4.607 BB | 0.2174 137.11986 | 8.81837 | 7.3633
9 | 5.093 BV | 0.2527 306.39346 | 15.36305 16.4532
10 | 5.574 VB | 0.0955 | 95.09799 | 15.09696 | 5.1067
11 | 7.392 BV | 0.5435 101.27338 | 2.78966 | 5.4383
12 | 8.875 VB | 1.1165 240.95953 | 2.77644 12.9394
13 11.601 BB | 0.3987 | 59.91646 | 2.60198 | 3.2175
14 12.907 BV | 0.4710 110.38485 | 3.69004 | 5.9276
15 13.655 VV | 0.4768 147.73592 | 4.23679 | 7.9334
16 14.581 VBA | 0.7439 178.31729 | 3.09144 | 9.5756
Totals : | 1862.21280 112.87447

===================================================================== *** End of Report ***

Data File F:\HPLC_Projects\Projects\Data\SHIBU SEQUENCE 2024-10-19 13-42-22\001-P1-A1-1.D Sample Name: 1

HPLC 19-10-2024 13:58:43 SYSTEM | Page | 2 | of | 2

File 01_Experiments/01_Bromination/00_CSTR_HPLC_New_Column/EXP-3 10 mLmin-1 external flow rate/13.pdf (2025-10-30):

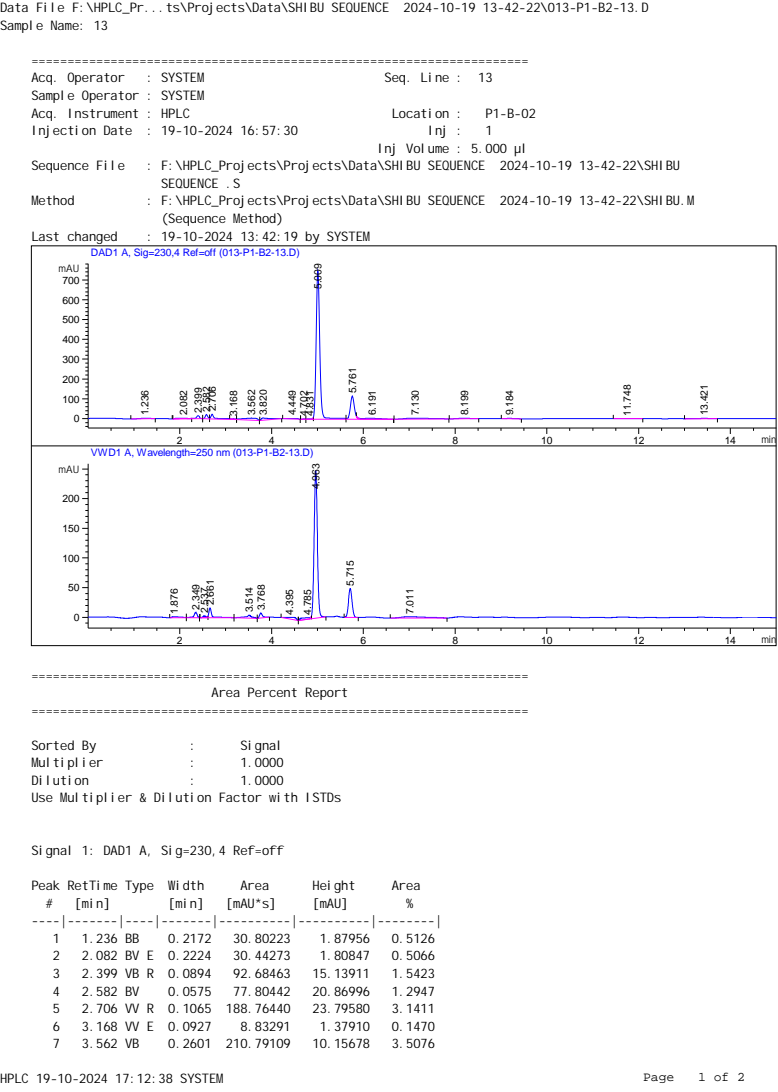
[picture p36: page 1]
Acq. Operator; : SYSTEM; Seq. Line : 13; Acq. Instrument : HPLC; Location :; Injection Date : 19-10-2024 16:57:30; Inj :; Sequence File; : F:\HPLC_Projects\Projects\Data\SHIBU SEQUENCE 2024-10-19 13-42-22\SHIBU; SEQUENCE .S; Method; : F:\HPLC_Projects\Projects\Data\SHIBU SEQUENCE 2024-10-19 13-42-22\SHIBU.M; (Sequence Method); Last changed; : 19-10-2024 13:42:19 by SYSTEM; min; mAU; VWD1 A, Wavelength=250 nm (013-P1-B2-13.D); Sorted By; Signal; Multiplier; Dilution; Peak RetTime Type Width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

Data File F:\HPLC_Pr...ts\Projects\Data\SHIBU SEQUENCE 2024-10-19 13-42-22\013-P1-B2-13.D
Sample Name: 13

Sample Operator : SYSTEM

Inj Volume : 5.000 µl

DAD1 A, Sig=230,4 Ref=off (013-P1-B2-13.D)

Area Percent Report

Use Multiplier & Dilution Factor with ISTDs

Signal 1: DAD1 A, Sig=230,4 Ref=off

Peak RetTime Type Width | Area | Height | Area
# | [min] | [min] | [mAU*s] | [mAU] | %

8 | 3.820 BB | 0.1734 133.61424 | 10.43474 | 2.2234
9 | 4.449 BB | 0.1910 | 45.74013 | 2.91650 | 0.7611
10 | 4.702 BV E 0.0819 | 8.08624 | 1.57569 | 0.1346
11 | 4.831 VV E 0.0989 | 12.75237 | 1.79431 | 0.2122
12 | 5.009 VV R 0.0832 4060.08496 748.97229 67.5603
13 | 5.761 VV R 0.0928 707.30103 116.54323 11.7696
14 | 6.191 VB E 0.3552 128.18915 | 4.48890 | 2.1331
15 | 7.130 BB | 0.4571 164.37289 | 4.34722 | 2.7352
16 | 8.199 BB | 0.2432 | 36.59943 | 1.91310 | 0.6090
17 | 9.184 BB | 0.2019 | 19.85731 | 1.30222 | 0.3304
18 11.748 BB | 0.2671 | 24.62109 | 1.11739 | 0.4097
19 13.421 BB | 0.2379 | 28.23420 | 1.58451 | 0.4698
Totals : | 6009.57545 972.01890

Signal 2: VWD1 A, Wavelength=250 nm

Peak RetTime Type Width | Area | Height | Area
# | [min] | [min] | [mAU*s] | [mAU] | %

1 | 1.876 BV | 0.1927 | 25.64561 | 1.83857 | 1.3335
2 | 2.349 VB | 0.0782 | 44.55534 | 8.77394 | 2.3167
3 | 2.537 BV E 0.0605 | 12.93750 | 3.17679 | 0.6727
4 | 2.661 VV R 0.0679 | 78.34121 | 16.63571 | 4.0735
5 | 3.514 BB | 0.1370 | 53.54225 | 5.12124 | 2.7840
6 | 3.768 BB | 0.0723 | 40.53811 | 8.40280 | 2.1079
7 | 4.395 BB | 0.2808 | 48.27058 | 2.80410 | 2.5099
8 | 4.785 BV E 0.1938 | 38.53209 | 2.54230 | 2.0036
9 | 4.963 VB R 0.0778 1230.25940 248.28192 63.9698
10 | 5.715 BB | 0.0843 264.00455 | 48.66915 13.7274
11 | 7.011 BB | 0.5402 | 86.56210 | 2.28376 | 4.5010
Totals : | 1923.18874 348.53029

===================================================================== *** End of Report ***

Data File F:\HPLC_Pr...ts\Projects\Data\SHIBU SEQUENCE 2024-10-19 13-42-22\013-P1-B2-13.D Sample Name: 13

HPLC 19-10-2024 17:12:38 SYSTEM | Page | 2 | of | 2

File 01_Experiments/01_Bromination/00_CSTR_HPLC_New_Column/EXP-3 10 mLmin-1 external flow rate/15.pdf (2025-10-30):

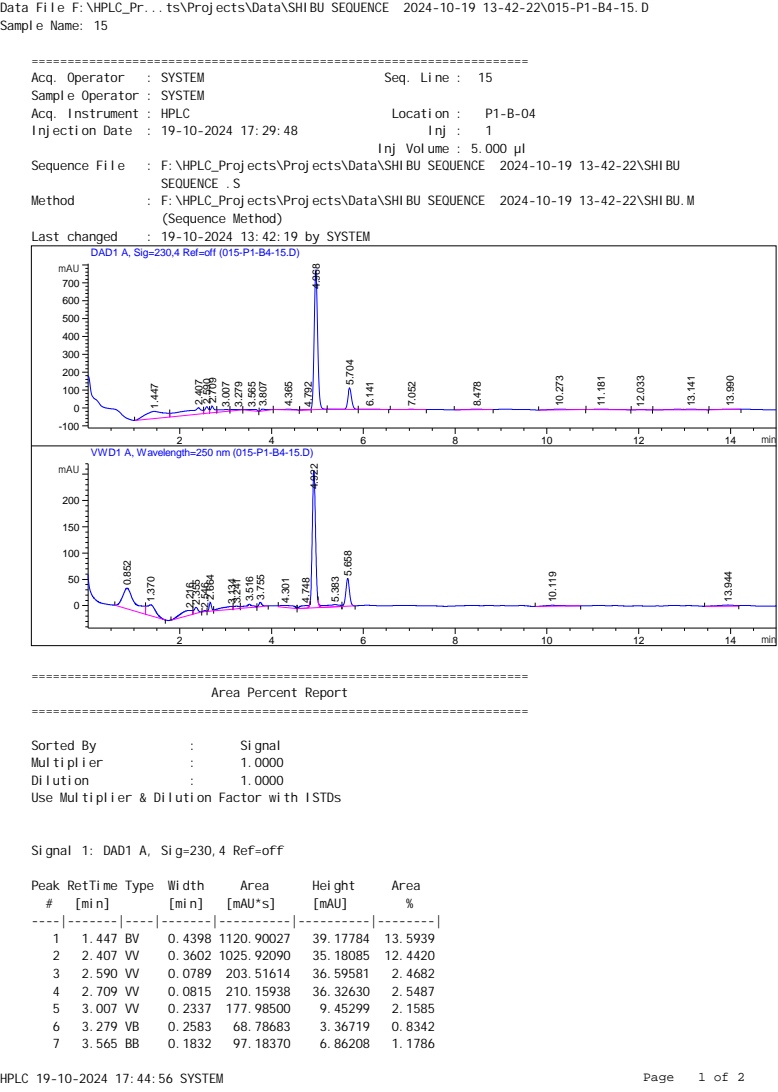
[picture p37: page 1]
Acq. Operator; : SYSTEM; Seq. Line : 15; Acq. Instrument : HPLC; Location :; Injection Date : 19-10-2024 17:29:48; Inj :; Sequence File; : F:\HPLC_Projects\Projects\Data\SHIBU SEQUENCE 2024-10-19 13-42-22\SHIBU; SEQUENCE .S; Method; : F:\HPLC_Projects\Projects\Data\SHIBU SEQUENCE 2024-10-19 13-42-22\SHIBU.M; (Sequence Method); Last changed; : 19-10-2024 13:42:19 by SYSTEM; min; mAU; VWD1 A, Wavelength=250 nm (015-P1-B4-15.D); Sorted By; Signal; Multiplier; Dilution; Peak RetTime Type Width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

Data File F:\HPLC_Pr...ts\Projects\Data\SHIBU SEQUENCE 2024-10-19 13-42-22\015-P1-B4-15.D
Sample Name: 15

Sample Operator : SYSTEM

Inj Volume : 5.000 µl

DAD1 A, Sig=230,4 Ref=off (015-P1-B4-15.D)

Area Percent Report

Use Multiplier & Dilution Factor with ISTDs

Signal 1: DAD1 A, Sig=230,4 Ref=off

Peak RetTime Type Width | Area | Height | Area
# | [min] | [min] | [mAU*s] | [mAU] | %

8 | 3.807 BB | 0.1235 | 87.91341 | 9.90928 | 1.0662
9 | 4.365 BB | 0.2808 | 72.31789 | 3.33792 | 0.8770
10 | 4.792 BV E 0.1405 | 27.84902 | 2.69658 | 0.3377
11 | 4.968 VB R 0.0802 4004.28052 776.12750 48.5626
12 | 5.704 VB R 0.0895 693.57178 119.83263 | 8.4114
13 | 6.141 BB | 0.2567 | 44.00215 | 2.16872 | 0.5336
14 | 7.052 BB | 0.3025 | 36.43824 | 1.53721 | 0.4419
15 | 8.478 BB | 0.3155 | 45.11205 | 1.71182 | 0.5471
16 10.273 BB | 0.4270 | 99.76302 | 2.77758 | 1.2099
17 11.181 BB | 0.3676 | 78.73592 | 2.59763 | 0.9549
18 12.033 BB | 0.1732 | 15.34224 | 1.12445 | 0.1861
19 13.141 BB | 0.5083 102.92712 | 2.41960 | 1.2483
20 13.990 BB | 0.2251 | 32.90803 | 1.87226 | 0.3991
Totals : | 8245.61360 1095.07625

Signal 2: VWD1 A, Wavelength=250 nm

Peak RetTime Type Width | Area | Height | Area
# | [min] | [min] | [mAU*s] | [mAU] | %

1 | 0.852 BV | 0.2654 729.22443 | 39.13083 20.7681
2 | 1.370 VB | 0.1852 272.88751 | 20.77820 | 7.7717
3 | 2.216 BV | 0.3229 173.60887 | 8.92661 | 4.9443
4 | 2.355 VB | 0.0873 | 67.01221 | 11.44903 | 1.9085
5 | 2.546 BB | 0.0459 | 6.28273 | 2.16299 | 0.1789
6 | 2.664 BV | 0.0536 | 57.60226 | 16.55162 | 1.6405
7 | 3.134 VV | 0.2444 107.31040 | 5.57820 | 3.0562
8 | 3.241 VV | 0.1218 | 44.59466 | 4.87219 | 1.2700
9 | 3.516 VB | 0.1522 | 76.55785 | 6.51154 | 2.1803
10 | 3.755 BB | 0.0724 | 37.61013 | 7.92217 | 1.0711
11 | 4.301 VB | 0.3400 | 78.33027 | 3.54143 | 2.2308
12 | 4.748 BV E 0.1627 | 59.03745 | 4.82530 | 1.6814
13 | 4.922 VV R 0.0773 1299.27795 260.20251 37.0030
14 | 5.383 VV E 0.2780 | 95.11041 | 4.31688 | 2.7087
15 | 5.658 VB | 0.0868 292.43329 | 52.68021 | 8.3284
16 10.119 BB | 0.4186 | 55.81256 | 1.89512 | 1.5895
17 13.944 BV | 0.3534 | 58.58615 | 2.31358 | 1.6685
Totals : | 3511.27914 453.65842

===================================================================== *** End of Report ***

Data File F:\HPLC_Pr...ts\Projects\Data\SHIBU SEQUENCE 2024-10-19 13-42-22\015-P1-B4-15.D Sample Name: 15

HPLC 19-10-2024 17:44:56 SYSTEM | Page | 2 | of | 2

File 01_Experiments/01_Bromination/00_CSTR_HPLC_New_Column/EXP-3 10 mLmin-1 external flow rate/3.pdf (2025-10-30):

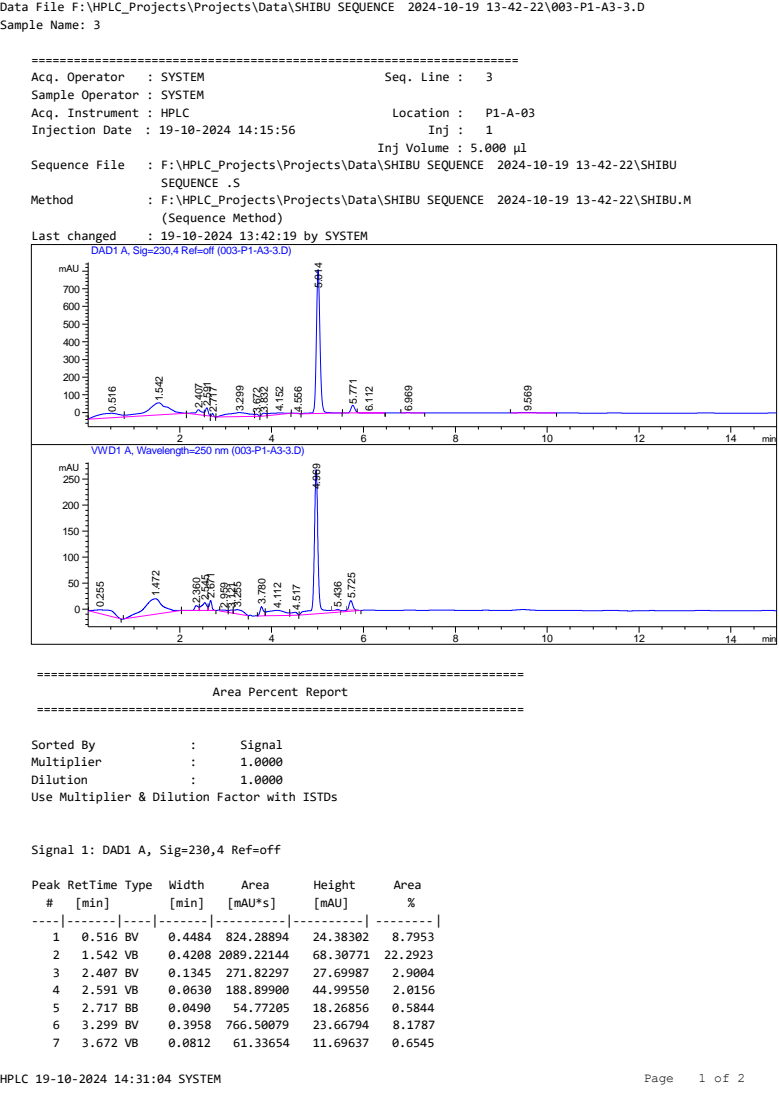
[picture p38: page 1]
HPLC 19-10-2024 14:31:04 SYSTEM; Page; Acq. Operator; : SYSTEM; Seq. Line :; Acq. Instrument : HPLC; Location :; Injection Date : 19-10-2024 14:15:56; Inj :; Sequence File; : F:\HPLC_Projects\Projects\Data\SHIBU SEQUENCE 2024-10-19 13-42-22\SHIBU; SEQUENCE .S; Method; : F:\HPLC_Projects\Projects\Data\SHIBU SEQUENCE 2024-10-19 13-42-22\SHIBU.M; (Sequence Method); Last changed; : 19-10-2024 13:42:19 by SYSTEM; Sorted By; Signal; Multiplier; Dilution; Peak RetTime Type; Width; Area; Height; [min]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

Data File F:\HPLC_Projects\Projects\Data\SHIBU SEQUENCE 2024-10-19 13-42-22\003-P1-A3-3.D
Sample Name: 3

Sample Operator : SYSTEM

Inj Volume : 5.000 µl

DAD1 A, Sig=230,4 Ref=off (003-P1-A3-3.D)

Area Percent Report

Use Multiplier & Dilution Factor with ISTDs

Signal 1: DAD1 A, Sig=230,4 Ref=off

Data File F:\HPLC_Projects\Projects\Data\SHIBU SEQUENCE 2024-10-19 13-42-22\003-P1-A3-3.D Sample Name: 3

HPLC 19-10-2024 14:31:04 SYSTEM | Page | 2 of 2

Signal 2: VWD1 A, Wavelength=250 nm

===================================================================== *** End of Report ***

Peak RetTime Type Width | Area | Height | Area
# | [min] | [min] | [mAU*s] | [mAU] | %

8 | 3.832 BV | 0.0952 100.40139 | 15.99580 | 1.0713
9 | 4.152 VB | 0.3226 | 228.83437 | 8.65139 | 2.4417
10 | 4.556 BB | 0.1036 | 18.85014 | 2.63089 | 0.2011
11 | 5.014 BB | 0.0827 3390.77148 816.67950 46.8502
12 | 5.771 BV R 0.0911 | 258.01697 | 43.57683 | 2.7531
13 | 6.112 VB E 0.2459 | 29.31391 | 1.47466 | 0.3128
14 | 6.969 BB | 0.1688 | 18.43252 | 1.50617 | 0.1967
15 | 9.569 BB | 0.2988 | 70.48067 | 3.01440 | 0.7520
Totals : | 8371.94316 1112.54861
Peak RetTime Type | Width | Area | Height | Area
# | [min] | [min] | [mAU*s] | [mAU] | %

1 | 0.255 BB | 0.5788 256.66312 | 6.83993 | 6.9273
2 | 1.472 BV R 0.4211 | 867.33630 | 29.92454 23.4092
3 | 2.360 BV | 0.0862 | 50.58393 | 9.19278 | 1.3652
4 | 2.545 VV | 0.1067 | 118.37297 | 15.05384 | 3.1949
5 | 2.671 VB | 0.0571 | 72.53762 | 19.18783 | 1.9578
6 | 2.959 VV | 0.1452 | 31.98862 | 3.10490 | 0.8634
7 | 3.121 VV | 0.0894 | 34.62496 | 5.42801 | 0.9345
8 | 3.255 VB | 0.1784 | 115.25118 | 8.38340 | 3.1106
9 | 3.780 BV | 0.0780 | 93.68320 | 17.61538 | 2.5285
10 | 4.112 VV | 0.3570 | 254.21265 | 9.98641 | 6.8611
11 | 4.517 VB | 0.1355 | 51.16940 | 5.45153 | 1.3810
12 | 4.969 BV R 0.0886 1653.82190 277.09781 44.6362
13 | 5.436 VV E 0.0742 | 8.99243 | 1.93392 | 0.2427
14 | 5.725 VB E 0.0824 | 95.87325 | 18.20426 | 2.5876
Totals : | 3705.11153 427.40455

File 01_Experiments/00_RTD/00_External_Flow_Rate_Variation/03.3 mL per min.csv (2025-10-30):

Timestamp | Time | Voltage Channel 0 | Voltage Channel 1 | Adjusted Voltage Channel 0 | Adjusted Voltage Channel 1
2024-10-18 22:02:27.751804 | 0,1953418254852295 | 3225 | 3550 | 0 | 0
2024-10-18 22:02:27.944988 | 0,39852094650268555 | 3226 | 3550 | -1 | 0
2024-10-18 22:02:28.148105 | 0,601637601852417 | 3226 | 3550 | -1 | 0
2024-10-18 22:02:28.351162 | 0,804694652557373 | 3226 | 3550 | -1 | 0
2024-10-18 22:02:28.563957 | 1,0067002773284912 | 3226 | 3550 | -1 | 0
2024-10-18 22:02:28.764063 | 1,2175960540771484 | 3226 | 3550 | -1 | 0
2024-10-18 22:02:28.967196 | 1,420729160308838 | 3226 | 3550 | -1 | 0
2024-10-18 22:02:29.170259 | 1,6237919330596924 | 3226 | 3550 | -1 | 0
2024-10-18 22:02:29.373527 | 1,8270597457885742 | 3226 | 3550 | -1 | 0
2024-10-18 22:02:29.576622 | 2,0301544666290283 | 3226 | 3550 | -1 | 0
2024-10-18 22:02:29.779781 | 2,23331356048584 | 3226 | 3550 | -1 | 0
2024-10-18 22:02:29.982864 | 2,436397075653076 | 3226 | 3550 | -1 | 0
2024-10-18 22:02:30.186449 | 2,639981269836426 | 3226 | 3550 | -1 | 0
2024-10-18 22:02:30.389946 | 2,8434791564941406 | 3225 | 3550 | 0 | 0
2024-10-18 22:02:30.593452 | 3,0469846725463867 | 3225 | 3550 | 0 | 0
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

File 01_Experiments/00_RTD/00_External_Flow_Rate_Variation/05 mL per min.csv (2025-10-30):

Timestamp | Time | Voltage Channel 0 | Voltage Channel 1 | Adjusted Voltage Channel 0 | Adjusted Voltage Channel 1
2024-10-18 16:32:30.424364 | 0,21368074417114258 | 2750 | 3539 | 0 | 0
2024-10-18 16:32:30.628372 | 0,4239811897277832 | 2750 | 3539 | 0 | 0
2024-10-18 16:32:30.816722 | 0,612729549407959 | 2749 | 3538 | 1 | 1
2024-10-18 16:32:31.018886 | 0,8164441585540771 | 2749 | 3538 | 1 | 1
2024-10-18 16:32:31.233873 | 1,021622896194458 | 2748 | 3538 | 2 | 1
2024-10-18 16:32:31.434566 | 1,2321252822875977 | 2748 | 3538 | 2 | 1
2024-10-18 16:32:31.637618 | 1,4351770877838135 | 2748 | 3538 | 2 | 1
2024-10-18 16:32:31.840810 | 1,638369083404541 | 2748 | 3538 | 2 | 1
2024-10-18 16:32:32.044325 | 1,841883897781372 | 2748 | 3538 | 2 | 1
2024-10-18 16:32:32.247440 | 2,044999122619629 | 2748 | 3538 | 2 | 1
2024-10-18 16:32:32.456524 | 2,2486469745635986 | 2748 | 3538 | 2 | 1
2024-10-18 16:32:32.655614 | 2,4531729221343994 | 2748 | 3537 | 2 | 2
2024-10-18 16:32:32.858743 | 2,6563022136688232 | 2748 | 3537 | 2 | 2
2024-10-18 16:32:33.061864 | 2,859422445297241 | 2748 | 3537 | 2 | 2
2024-10-18 16:32:33.265551 | 3,0631093978881836 | 2749 | 3538 | 1 | 1
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

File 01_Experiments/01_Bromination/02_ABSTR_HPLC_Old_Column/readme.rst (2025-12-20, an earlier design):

HPLC Data Using Old Column
==========================

This directory contains HPLC chromatograms data collected using the **old HPLC column.**.The data include calibration measurements,
ABSTR batch reaction studies,optimization experimentation and scale up under different operating conditions.

The folder structure is organized based on reaction duration, flow conditions,
concentration optimization, and scale-up studies.

Folder Structure and Description
--------------------------------

1 h Reaction
~~~~~~~~~~~~
This folder contains HPLC data from **ABSTR batch reaction performed for a definite number of reaction cycles completed within 1 hour.** for two different concentrations of the reactant.
(500mM and 815mM)

---

500mM
-----

this folder contains HPLC chromatograms for the 1 hour ABSTR operation when reactant concentration was 500mM with each bach operation time with 6 minute 40 second.

Each PDF file represents the reactant composition sampled after a specific reaction time.

File naming Conversion
~~~~~~~~~~~~~~~~~~~~~~

- 1.pdf -->sample collected after 400 sec of reaction

- 2.pdf -->sample collected after 800 sec of reaction

similarly upto 3600 second with the interval of 400sec 

815mM
~~~~~

this folder contains HPLC chromatograms for the 1 hour ABSTR operation when reactant concentration was 815mM with each batch operation time with 8 minute 40 second.

Each PDF file represents the reactant composition sampled after a specific reaction time.

File naming Conversion
~~~~~~~~~~~~~~~~~~~~~~

- 1.pdf -->sample collected after 520 sec of reaction

- 2.pdf -->sample collected after 1040 second of reaction

similayly upto 3640 second with the interval of 520 second

24 h Reaction
~~~~~~~~~~~~~

This folder contains HPLC data from **ABSTR batch reaction performed for a definite number of reaction cycles completed within 24 hour.** for two different concentrations of the reactant
(500mM and 815mM).

---

500mM
-----

this folder contains HPLC chromatograms for the 24 hour ABSTR operation when reactant concentration was 500mM with each bach operation time with 10 minute 40 second.

Each PDF file represents the reactant composition sampled after a specific reaction time.

File naming Conversion
~~~~~~~~~~~~~~~~~~~~~~

- 1.pdf -->sample collected after 4 hour of reaction

- 2.pdf -->sample collected after 8 hour of reaction

similarly upto 24 hour with the interval of 4 hour .

815mM
~~~~~

this folder contains HPLC chromatograms for the 24 hour ABSTR operation when reactant concentration was 815mM with each batch operation time with 12 minute 40 second.

Each PDF file represents the reactant composition sampled after a specific reaction time.

File naming Conversion
~~~~~~~~~~~~~~~~~~~~~~

- 1.pdf -->sample collected after 4 hour of reaction

- 2.pdf -->sample collected after 4 hour of reaction

similayly upto 24 hour with the interval of 4 hour

---

Different Internal Flow Rate
~~~~~~~~~~~~~~~~~~~~~~~~~~~~

This folder contains batch reaction data collected while varying the
**internal looping flow rate**.

- These experiments were performed to study the effect of internal circulation
  on reaction performance.
- Subfolders represent different internal flow-rate conditions and reactant
  concentrations.

500mM scale with out looping operation
~~~~~~~~~~~~~~~~~~~~~~~~~~~~~~~~~~~~~~

This folder contains batch reaction data for the 500 mM reactant concentration and without any looping operation.

File naming convention
~~~~~~~~~~~~~~~~~~~~~~

- 1.pdf -->sample collected after 2 minute of reaction

- 2.pdf -->sample collected after 4 minute of reaction

similarly upto 12 minute the interval of 2 minute .

500mM scale  with a space velocity of 150mL.min⁻¹
~~~~~~~~~~~~~~~~~~~~~~~~~~~~~~~~~~~~~~~~~~~~~~~~~

This folder contains batch reaction data for the 500 mM reactant concentration with space velocity of 150mL.min⁻¹

File naming convention
~~~~~~~~~~~~~~~~~~~~~~

- 1.pdf -->sample collected after 2 minute of reaction

- 2.pdf -->sample collected after 4 minute of reaction

similarly upto 12 minute the interval of 2 minute .

500mM scale  with a space velocity of 300mL.min⁻¹
~~~~~~~~~~~~~~~~~~~~~~~~~~~~~~~~~~~~~~~~~~~~~~~~~

This folder contains batch reaction data for the 500 mM reactant concentration with space velocity of 300mL.min⁻¹

File naming convention
~~~~~~~~~~~~~~~~~~~~~~

- 1.pdf -->sample collected after 2 minute of reaction

- 2.pdf -->sample collected after 4 minute of reaction

similarly upto 12 minute the interval of 2 minute .

815mM scale with out looping operation
~~~~~~~~~~~~~~~~~~~~~~~~~~~~~~~~~~~~~~

This folder contains batch reaction data for the 815 mM reactant concentration and without any looping operation.

File naming convention
~~~~~~~~~~~~~~~~~~~~~~

- 1.pdf -->sample collected after 2 minute of reaction

- 2.pdf -->sample collected after 4 minute of reaction

similarly upto 12 minute the interval of 2 minute .

815mM scale  with a space velocity of 150mL.min⁻¹
~~~~~~~~~~~~~~~~~~~~~~~~~~~~~~~~~~~~~~~~~~~~~~~~~

This folder contains batch reaction data for the 815 mM reactant concentration with space velocity of 150mL.min⁻¹

File naming convention
~~~~~~~~~~~~~~~~~~~~~~

- 1.pdf -->sample collected after 2 minute of reaction

- 2.pdf -->sample collected after 4 minute of reaction

similarly upto 12 minute the interval of 2 minute .

815mM scale  with a space velocity of 300mL.min⁻¹
~~~~~~~~~~~~~~~~~~~~~~~~~~~~~~~~~~~~~~~~~~~~~~~~~

This folder contains batch reaction data for the 815 mM reactant concentration with space velocity of 300mL.min⁻¹

File naming convention
~~~~~~~~~~~~~~~~~~~~~~

- 1.pdf -->sample collected after 2 minute of reaction

- 2.pdf -->sample collected after 4 minute of reaction

similarly upto 12 minute the interval of 2 minute .

---

Optimization with Respect to Different Concentration
~~~~~~~~~~~~~~~~~~~~~~~~~~~~~~~~~~~~~~~~~~~~~~~~~~~~

This folder contains HPLC data from **optimization** studies performed at different
reactant concentrations**(500mM and 815mM).

- Each subfolder corresponds to a specific concentration used during the batch
  reaction.
- Experiments include 10mL batch reaction with space velocity 15min⁻¹(150 mL per minute internal flowrate)

500mM Scale
~~~~~~~~~~~
this folder contains hplc data of the optimization reaction at 500mM scale.Reaction volume 10mL and space veclocity 15 min⁻¹

File naming convention
~~~~~~~~~~~~~~~~~~~~~~

- 1.pdf -->sample collected after 2 minute of reaction

- 2.pdf -->sample collected after 4 minute of reaction

similarly upto 12 minute the interval of 2 minute .

815mM scale
~~~~~~~~~~~

this folder contains hplc data of the optimization reaction at 815mM scale.Reaction volume 10mL and space veclocity 15 min⁻¹

File naming convention
~~~~~~~~~~~~~~~~~~~~~~

- 1.pdf -->sample collected after 2 minute of reaction

- 2.pdf -->sample collected after 4 minute of reaction

similarly upto 12 minute the interval of 2 minute .

Scale-Up
~~~~~~~~

This folder contains HPLC data from **scale-up experiments** performed for the
automated batch process using the old column.

- **Reactant Concentration** :500mM
- **Photon Flux used** :185 µmolsec⁻¹
- **space velocity**:15 min⁻¹ with total operation time of 1 hour where each batch cycle time was 6 minute 40 second

- The experiments were conducted at a larger operational scale.

File naming convention
~~~~~~~~~~~~~~~~~~~~~~

- 1.pdf -->sample collected after first batch cycle of the reaction

- 2.pdf -->sample collected after second batch cycle of the reaction 

similarly upto 9th batch cycle of the reaction

---

Std. Graph (Standard Calibration Data)
~~~~~~~~~~~~~~~~~~~~~~~~~~~~~~~~~~~~~~
This folder contains **standard calibration chromatograms** for the old HPLC
column.

- Each PDF corresponds to a peak area of a standard Benzyl Bromide solution with a known concentration.

- File names indicate the concentration value associated with the standard.

**Examples:**

- ``1.25.pdf`` → Standard solution with a concentration of **1.25 microgram per mL**  
- ``2.50.pdf`` → Standard solution with a concentration of **2.50 microgram per mL**  
- ``5.00.pdf`` → Standard solution with a concentration of **5.00 microgram per mL**

Notes
-----
- All data in this directory were collected using the old HPLC column.
- Experimental conditions other than those specified were kept constant unless
  stated otherwise.

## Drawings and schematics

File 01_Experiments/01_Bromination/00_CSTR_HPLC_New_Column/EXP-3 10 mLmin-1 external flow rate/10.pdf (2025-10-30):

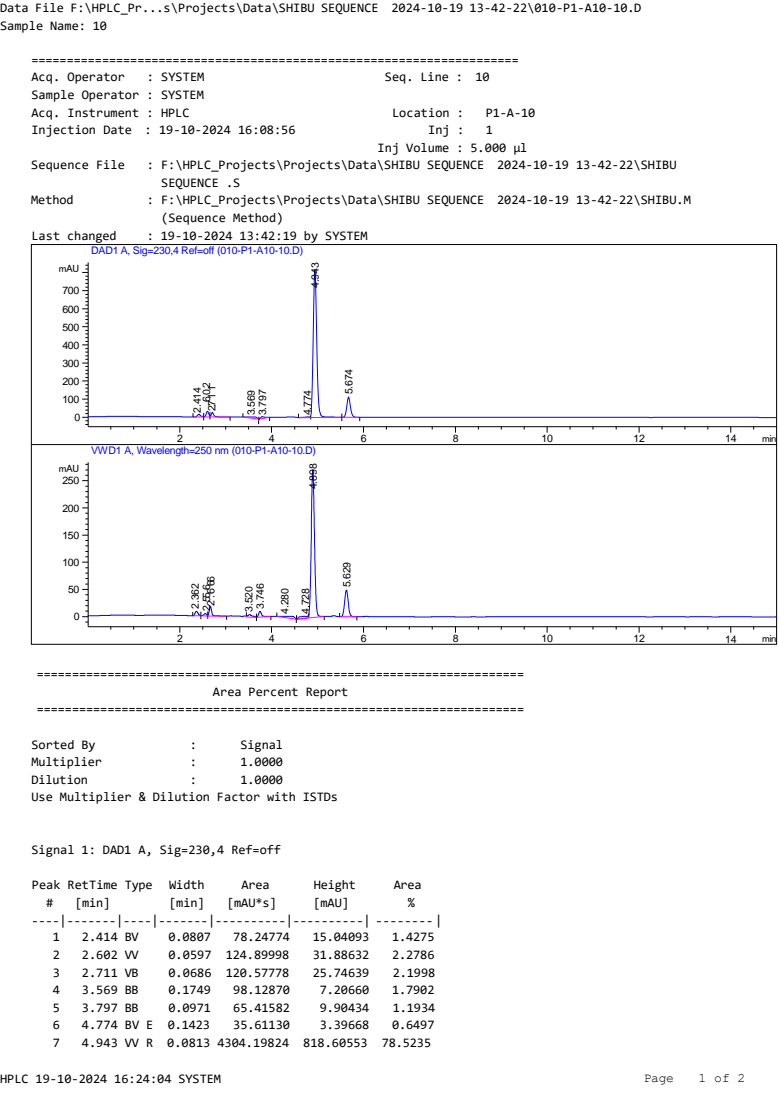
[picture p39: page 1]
HPLC 19-10-2024 16:24:04 SYSTEM; Page; Acq. Operator; : SYSTEM; Seq. Line : 10; Acq. Instrument : HPLC; Location :; Injection Date : 19-10-2024 16:08:56; Inj :; Sequence File; : F:\HPLC_Projects\Projects\Data\SHIBU SEQUENCE 2024-10-19 13-42-22\SHIBU; SEQUENCE .S; Method; : F:\HPLC_Projects\Projects\Data\SHIBU SEQUENCE 2024-10-19 13-42-22\SHIBU.M; (Sequence Method); Last changed; : 19-10-2024 13:42:19 by SYSTEM; Sorted By; Signal; Multiplier; Dilution; Peak RetTime Type; Width; Area; Height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

Data File F:\HPLC_Pr...s\Projects\Data\SHIBU SEQUENCE 2024-10-19 13-42-22\010-P1-A10-10.D
Sample Name: 10

Sample Operator : SYSTEM

Inj Volume : 5.000 µl

DAD1 A, Sig=230,4 Ref=off (010-P1-A10-10.D)

Area Percent Report

Use Multiplier & Dilution Factor with ISTDs

Signal 1: DAD1 A, Sig=230,4 Ref=off

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

HPLC 19-10-2024 16:24:04 SYSTEM | Page | 2 of 2
Peak RetTime Type Width | Area | Height | Area
# | [min] | [min] | [mAU*s] | [mAU] | %

8 | 5.674 VB | 0.0895 654.33380 | 113.12071 11.9373
Totals : | 5481.41336 1024.90749

Signal 2: VWD1 A, Wavelength=250 nm

===================================================================== *** End of Report ***

Peak RetTime Type | Width | Area | Height | Area
# | [min] | [min] | [mAU*s] | [mAU] | %

1 | 2.362 BV | 0.0761 | 37.66942 | 7.97867 | 1.9683
2 | 2.556 VV | 0.0640 | 20.00086 | 4.57697 | 1.0451
3 | 2.666 VB | 0.0564 | 65.47392 | 17.60764 | 3.4212
4 | 3.520 VB | 0.0927 | 32.38517 | 4.85988 | 1.6922
5 | 3.746 BB | 0.0724 | 51.06689 | 10.56185 | 2.6684
6 | 4.280 BB | 0.3233 | 54.11679 | 2.08146 | 2.8278
7 | 4.728 BV E 0.1672 | 43.80600 | 3.42567 | 2.2890
8 | 4.898 VB R 0.0766 1344.13452 272.03806 70.2348
9 | 5.629 BB | 0.0845 | 265.11984 | 48.73836 13.8533
Totals : | 1913.77341 371.86855

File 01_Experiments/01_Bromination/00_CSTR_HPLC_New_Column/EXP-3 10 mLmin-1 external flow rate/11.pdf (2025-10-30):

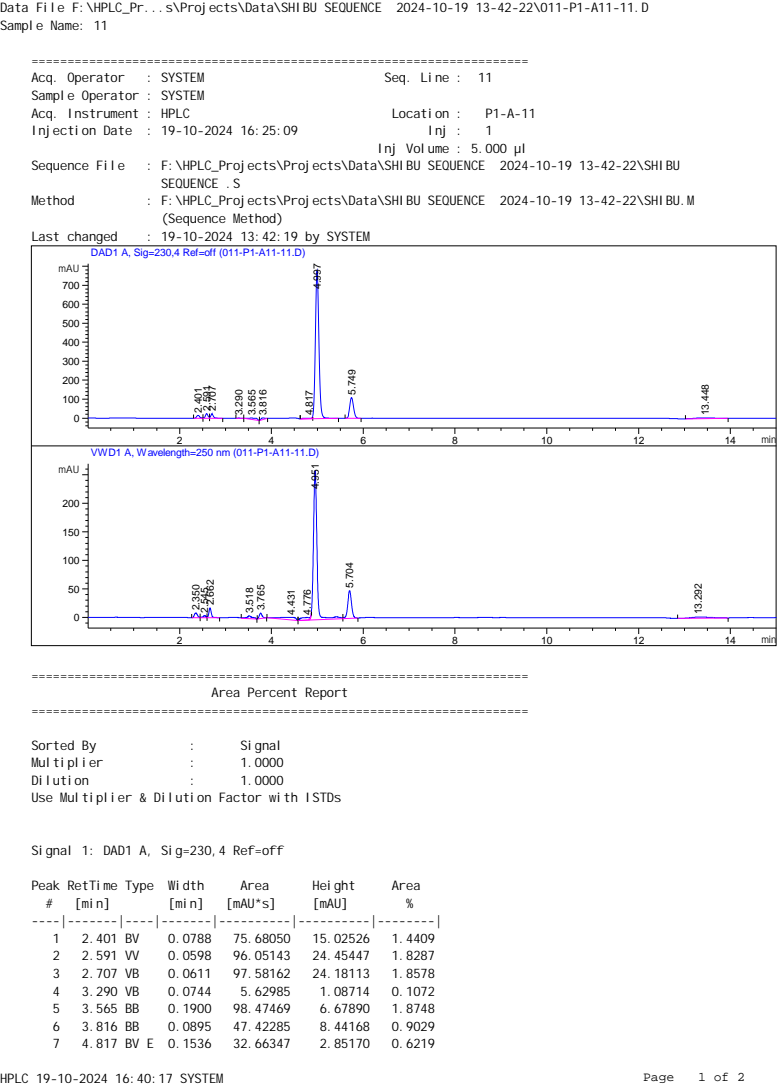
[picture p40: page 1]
Acq. Operator; : SYSTEM; Seq. Line : 11; Acq. Instrument : HPLC; Location :; Injection Date : 19-10-2024 16:25:09; Inj :; Sequence File; : F:\HPLC_Projects\Projects\Data\SHIBU SEQUENCE 2024-10-19 13-42-22\SHIBU; SEQUENCE .S; Method; : F:\HPLC_Projects\Projects\Data\SHIBU SEQUENCE 2024-10-19 13-42-22\SHIBU.M; (Sequence Method); Last changed; : 19-10-2024 13:42:19 by SYSTEM; min; mAU; VWD1 A, Wavelength=250 nm (011-P1-A11-11.D); Sorted By; Signal; Multiplier; Dilution; Peak RetTime Type Width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

Data File F:\HPLC_Pr...s\Projects\Data\SHIBU SEQUENCE 2024-10-19 13-42-22\011-P1-A11-11.D
Sample Name: 11

Sample Operator : SYSTEM

Inj Volume : 5.000 µl

DAD1 A, Sig=230,4 Ref=off (011-P1-A11-11.D)

Area Percent Report

Use Multiplier & Dilution Factor with ISTDs

Signal 1: DAD1 A, Sig=230,4 Ref=off

Peak RetTime Type Width | Area | Height | Area
# | [min] | [min] | [mAU*s] | [mAU] | %

8 | 4.997 VB R 0.0810 4073.46338 778.65796 77.5539
9 | 5.749 BB | 0.0887 627.83624 109.75009 11.9533
10 13.448 BB | 0.3538 | 97.62411 | 3.37135 | 1.8586
Totals : | 5252.42814 974.49967

Signal 2: VWD1 A, Wavelength=250 nm

Peak RetTime Type Width | Area | Height | Area
# | [min] | [min] | [mAU*s] | [mAU] | %

1 | 2.350 BV | 0.0752 | 37.79013 | 8.13131 | 1.8146
2 | 2.545 VV | 0.0658 | 15.73676 | 3.54388 | 0.7556
3 | 2.662 VB | 0.0537 | 58.73579 | 16.82515 | 2.8203
4 | 3.518 VB | 0.1183 | 44.45261 | 5.01989 | 2.1345
5 | 3.765 BB | 0.0680 | 41.21172 | 9.42799 | 1.9789
6 | 4.431 BB | 0.3162 | 97.79750 | 4.22228 | 4.6959
7 | 4.776 BV E 0.1711 | 58.02053 | 4.42079 | 2.7860
8 | 4.951 VV R 0.0822 1391.42212 260.88998 66.8116
9 | 5.704 VB | 0.0873 275.24017 | 48.46518 13.2162
10 13.292 BV | 0.4460 | 62.19731 | 1.87037 | 2.9865
Totals : | 2082.60463 362.81683

===================================================================== *** End of Report ***

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

HPLC 19-10-2024 16:40:17 SYSTEM | Page | 2 | of | 2

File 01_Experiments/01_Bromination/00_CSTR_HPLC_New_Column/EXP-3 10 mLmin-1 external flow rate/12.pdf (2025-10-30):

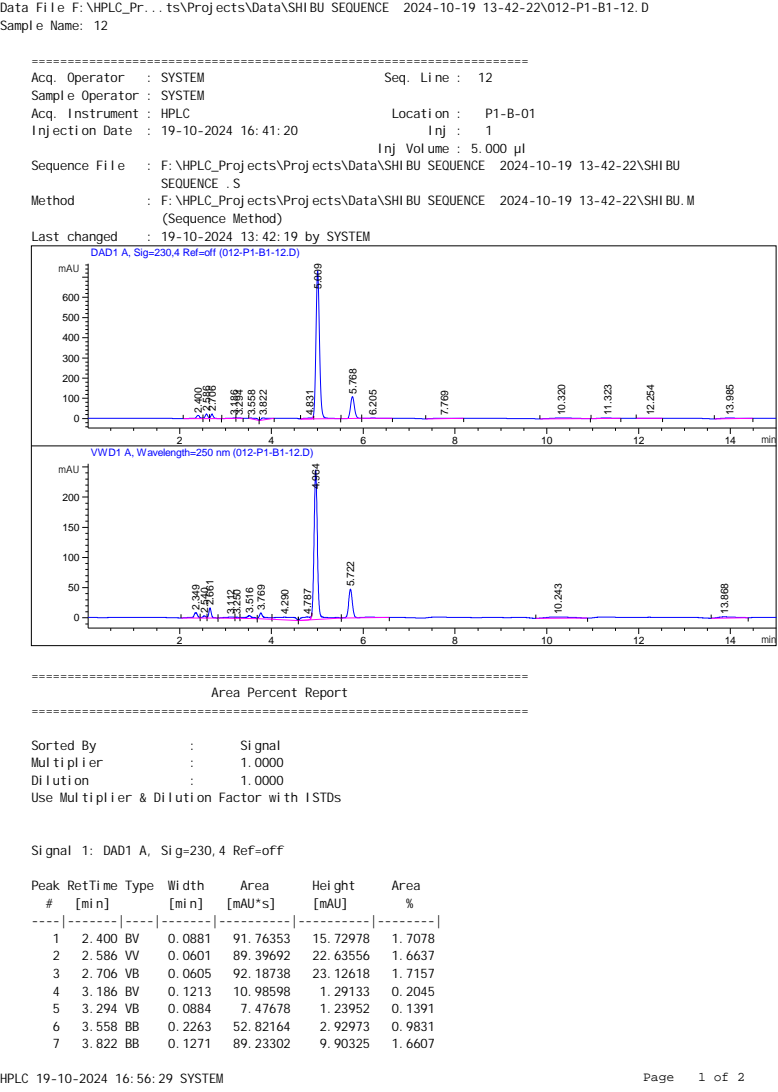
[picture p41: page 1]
Acq. Operator; : SYSTEM; Seq. Line : 12; Acq. Instrument : HPLC; Location :; Injection Date : 19-10-2024 16:41:20; Inj :; Sequence File; : F:\HPLC_Projects\Projects\Data\SHIBU SEQUENCE 2024-10-19 13-42-22\SHIBU; SEQUENCE .S; Method; : F:\HPLC_Projects\Projects\Data\SHIBU SEQUENCE 2024-10-19 13-42-22\SHIBU.M; (Sequence Method); Last changed; : 19-10-2024 13:42:19 by SYSTEM; min; mAU; VWD1 A, Wavelength=250 nm (012-P1-B1-12.D); Sorted By; Signal; Multiplier; Dilution; Peak RetTime Type Width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

Data File F:\HPLC_Pr...ts\Projects\Data\SHIBU SEQUENCE 2024-10-19 13-42-22\012-P1-B1-12.D
Sample Name: 12

Sample Operator : SYSTEM

Inj Volume : 5.000 µl

DAD1 A, Sig=230,4 Ref=off (012-P1-B1-12.D)

Area Percent Report

Use Multiplier & Dilution Factor with ISTDs

Signal 1: DAD1 A, Sig=230,4 Ref=off

Peak RetTime Type Width | Area | Height | Area
# | [min] | [min] | [mAU*s] | [mAU] | %

8 | 4.831 BV E 0.1414 | 48.96796 | 4.62967 | 0.9113
9 | 5.009 VB R 0.0815 3876.90674 734.87488 72.1522
10 | 5.768 BB | 0.0892 628.26544 109.02803 11.6925
11 | 6.205 BB | 0.2148 | 26.44310 | 1.53600 | 0.4921
12 | 7.769 BB | 0.3523 | 58.25558 | 1.98569 | 1.0842
13 10.320 BB | 0.4375 146.72050 | 4.00452 | 2.7306
14 11.323 BB | 0.2803 | 54.19905 | 2.50594 | 1.0087
15 12.254 BB | 0.2235 | 21.92420 | 1.17584 | 0.4080
16 13.985 BB | 0.3292 | 77.68788 | 2.91212 | 1.4458
Totals : | 5373.23569 939.50804

Signal 2: VWD1 A, Wavelength=250 nm

Peak RetTime Type Width | Area | Height | Area
# | [min] | [min] | [mAU*s] | [mAU] | %

1 | 2.349 BV | 0.0864 | 49.82072 | 8.75227 | 2.3154
2 | 2.540 VV | 0.0672 | 16.04049 | 3.45229 | 0.7455
3 | 2.661 VB | 0.0540 | 57.06940 | 16.24325 | 2.6522
4 | 3.112 BV | 0.1691 | 23.75281 | 1.87055 | 1.1039
5 | 3.250 VV | 0.0866 | 10.82650 | 1.71535 | 0.5031
6 | 3.516 VB | 0.1296 | 49.13827 | 5.00287 | 2.2836
7 | 3.769 BV | 0.1044 | 70.81442 | 9.34799 | 3.2910
8 | 4.290 VB | 0.3673 127.56947 | 4.33469 | 5.9286
9 | 4.787 BV E 0.1671 | 62.51090 | 4.92537 | 2.9051
10 | 4.964 VV R 0.0796 1275.92163 245.75635 59.2969
11 | 5.722 BV R 0.0916 282.65579 | 47.36601 13.1361
12 10.243 BB | 0.5599 | 82.06396 | 2.15202 | 3.8138
13 13.868 BB | 0.3527 | 43.56557 | 1.81087 | 2.0247
Totals : | 2151.74996 352.72986

===================================================================== *** End of Report ***

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

HPLC 19-10-2024 16:56:29 SYSTEM | Page | 2 | of | 2

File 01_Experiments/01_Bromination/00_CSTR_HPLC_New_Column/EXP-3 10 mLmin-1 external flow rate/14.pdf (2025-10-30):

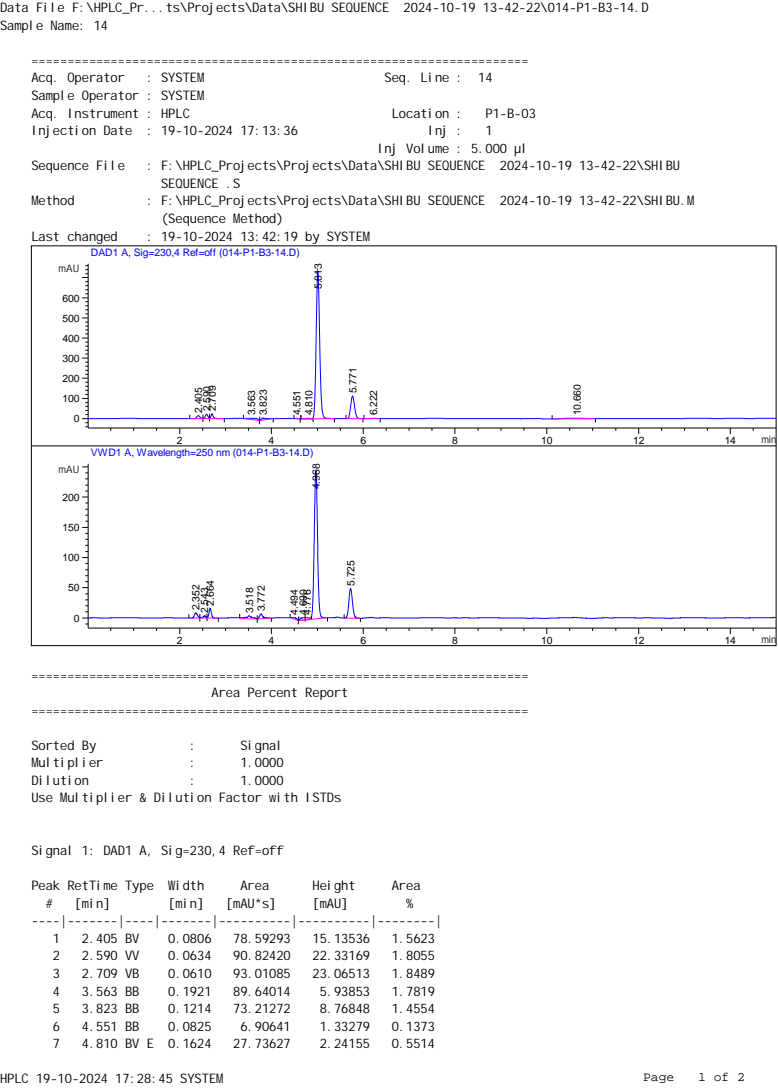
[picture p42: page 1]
Acq. Operator; : SYSTEM; Seq. Line : 14; Acq. Instrument : HPLC; Location :; Injection Date : 19-10-2024 17:13:36; Inj :; Sequence File; : F:\HPLC_Projects\Projects\Data\SHIBU SEQUENCE 2024-10-19 13-42-22\SHIBU; SEQUENCE .S; Method; : F:\HPLC_Projects\Projects\Data\SHIBU SEQUENCE 2024-10-19 13-42-22\SHIBU.M; (Sequence Method); Last changed; : 19-10-2024 13:42:19 by SYSTEM; min; mAU; VWD1 A, Wavelength=250 nm (014-P1-B3-14.D); Sorted By; Signal; Multiplier; Dilution; Peak RetTime Type Width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

Data File F:\HPLC_Pr...ts\Projects\Data\SHIBU SEQUENCE 2024-10-19 13-42-22\014-P1-B3-14.D
Sample Name: 14

Sample Operator : SYSTEM

Inj Volume : 5.000 µl

DAD1 A, Sig=230,4 Ref=off (014-P1-B3-14.D)

Area Percent Report

Use Multiplier & Dilution Factor with ISTDs

Signal 1: DAD1 A, Sig=230,4 Ref=off

Peak RetTime Type Width | Area | Height | Area
# | [min] | [min] | [mAU*s] | [mAU] | %

8 | 5.013 VB R 0.0809 3830.04688 734.00739 76.1365
9 | 5.771 BB | 0.0892 647.87463 112.51431 12.8789
10 | 6.222 BB | 0.1461 | 14.34219 | 1.34855 | 0.2851
11 10.660 BB | 0.3509 | 78.31180 | 2.82969 | 1.5567
Totals : | 5030.49902 929.51347

Signal 2: VWD1 A, Wavelength=250 nm

Peak RetTime Type Width | Area | Height | Area
# | [min] | [min] | [mAU*s] | [mAU] | %

1 | 2.352 BV | 0.0742 | 38.75772 | 8.33793 | 2.2133
2 | 2.543 VV | 0.0690 | 16.48131 | 3.43605 | 0.9412
3 | 2.664 VB | 0.0543 | 57.19199 | 16.15166 | 3.2660
4 | 3.518 VB | 0.1262 | 48.43820 | 5.03541 | 2.7661
5 | 3.772 BB | 0.0761 | 40.47989 | 7.99500 | 2.3116
6 | 4.494 BB | 0.1068 | 15.21331 | 2.19628 | 0.8688
7 | 4.690 BV E 0.1054 | 24.23300 | 3.65331 | 1.3838
8 | 4.776 VV E 0.0916 | 19.46653 | 3.04544 | 1.1116
9 | 4.968 VB R 0.0773 1222.10791 244.59195 69.7890
10 | 5.725 BB | 0.0862 268.77606 | 48.81850 15.3486
Totals : | 1751.14592 343.26153

===================================================================== *** End of Report ***

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

HPLC 19-10-2024 17:28:45 SYSTEM | Page | 2 | of | 2

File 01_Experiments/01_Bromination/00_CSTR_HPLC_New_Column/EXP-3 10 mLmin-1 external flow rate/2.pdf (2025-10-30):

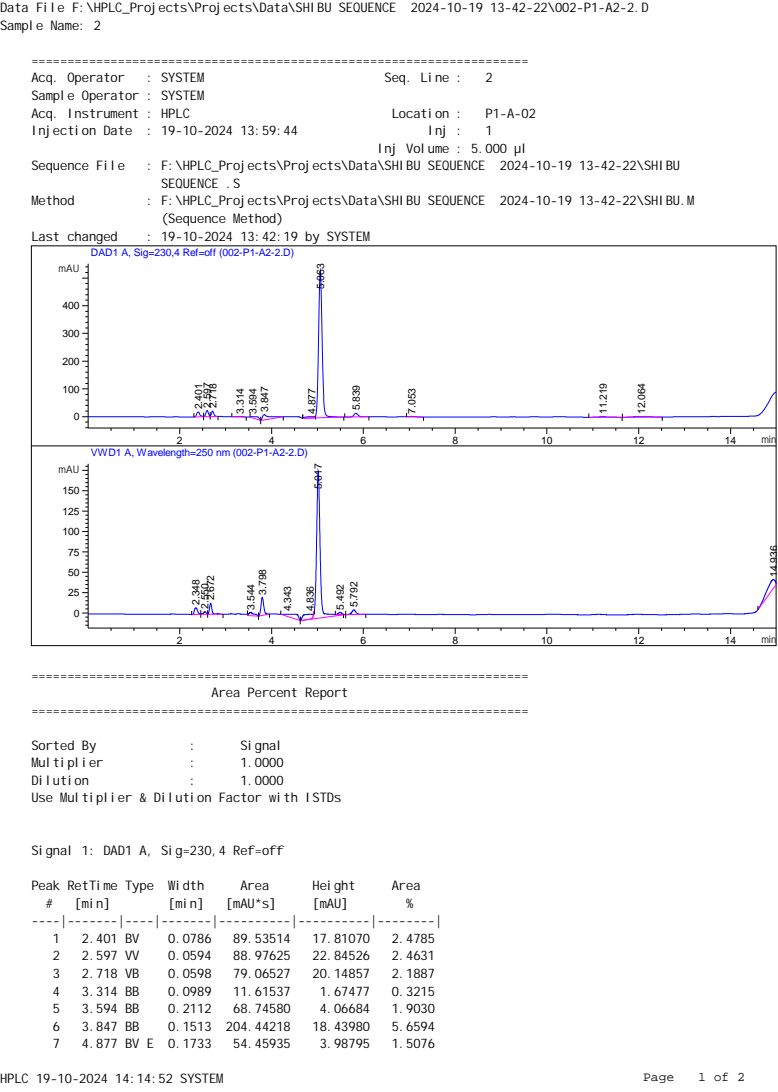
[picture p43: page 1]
Acq. Operator; : SYSTEM; Seq. Line :; Acq. Instrument : HPLC; Location :; Injection Date : 19-10-2024 13:59:44; Inj :; Sequence File; : F:\HPLC_Projects\Projects\Data\SHIBU SEQUENCE 2024-10-19 13-42-22\SHIBU; SEQUENCE .S; Method; : F:\HPLC_Projects\Projects\Data\SHIBU SEQUENCE 2024-10-19 13-42-22\SHIBU.M; (Sequence Method); Last changed; : 19-10-2024 13:42:19 by SYSTEM; min; mAU; VWD1 A, Wavelength=250 nm (002-P1-A2-2.D); Sorted By; Signal; Multiplier; Dilution; Peak RetTime Type Width; Area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

Data File F:\HPLC_Projects\Projects\Data\SHIBU SEQUENCE 2024-10-19 13-42-22\002-P1-A2-2.D
Sample Name: 2

Sample Operator : SYSTEM

Inj Volume : 5.000 µl

DAD1 A, Sig=230,4 Ref=off (002-P1-A2-2.D)

Area Percent Report

Use Multiplier & Dilution Factor with ISTDs

Signal 1: DAD1 A, Sig=230,4 Ref=off

Peak RetTime Type Width | Area | Height | Area
# | [min] | [min] | [mAU*s] | [mAU] | %

8 | 5.063 VB R 0.0826 2840.08838 529.18573 78.6198
9 | 5.839 BB | 0.0951 | 81.53719 | 13.00444 | 2.2571
10 | 7.053 BB | 0.1131 | 9.74178 | 1.30505 | 0.2697
11 11.219 BB | 0.2570 | 34.07288 | 1.64971 | 0.9432
12 12.064 BB | 0.3181 | 50.15421 | 1.96271 | 1.3884
Totals : | 3612.43381 636.08155

Signal 2: VWD1 A, Wavelength=250 nm

Peak RetTime Type Width | Area | Height | Area
# | [min] | [min] | [mAU*s] | [mAU] | %

1 | 2.348 BV | 0.0764 | 38.72800 | 8.15838 | 2.4308
2 | 2.550 VV | 0.0648 | 14.98595 | 3.37310 | 0.9406
3 | 2.672 VV R 0.0565 | 50.25406 | 13.47976 | 3.1543
4 | 3.544 VB | 0.1076 | 33.75316 | 4.25116 | 2.1186
5 | 3.798 BB | 0.0663 | 95.94344 | 22.23439 | 6.0221
6 | 4.343 BB | 0.3729 | 81.27651 | 2.67935 | 5.1015
7 | 4.836 BV E 0.1900 | 86.48344 | 5.83201 | 5.4283
8 | 5.017 VV R 0.0832 992.08014 180.40154 62.2700
9 | 5.492 VB E 0.0768 | 12.29916 | 2.52521 | 0.7720
10 | 5.792 BB | 0.0924 | 34.40681 | 5.70359 | 2.1596
11 14.936 BBA | 0.2443 152.97958 | 10.43499 | 9.6021
Totals : | 1593.19025 259.07348

===================================================================== *** End of Report ***

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

HPLC 19-10-2024 14:14:52 SYSTEM | Page | 2 | of | 2

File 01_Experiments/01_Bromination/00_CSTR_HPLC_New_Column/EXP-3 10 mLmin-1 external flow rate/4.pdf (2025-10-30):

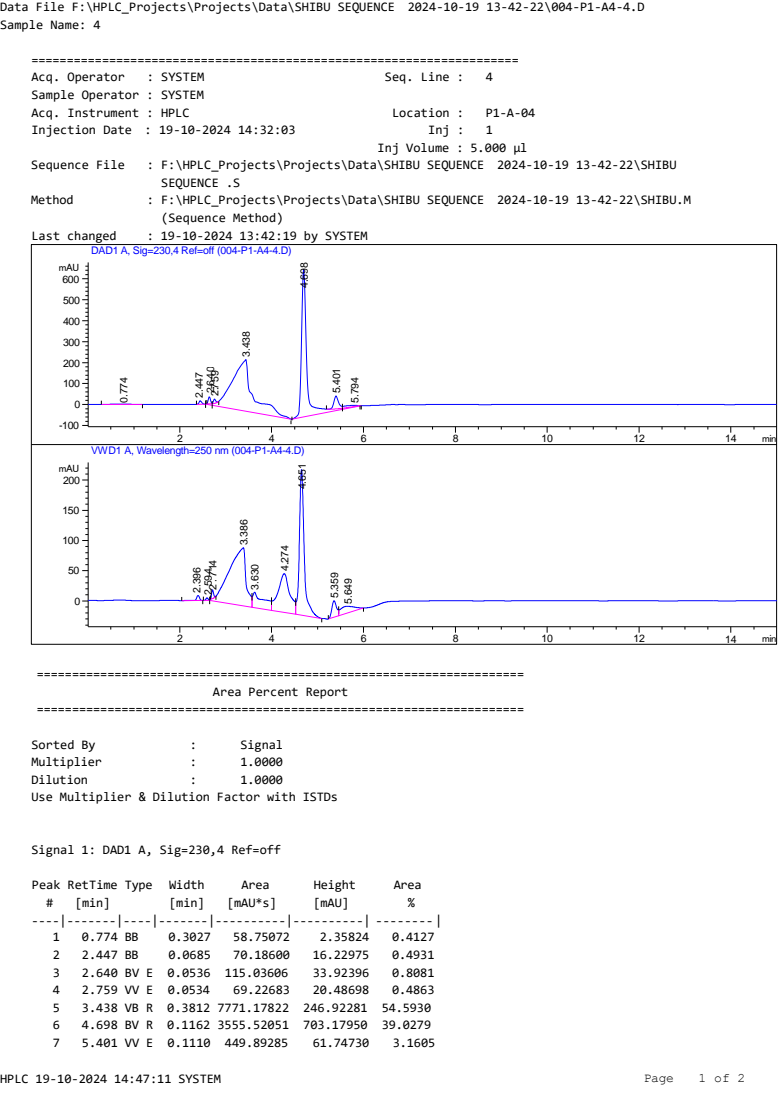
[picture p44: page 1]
HPLC 19-10-2024 14:47:11 SYSTEM; Page; Acq. Operator; : SYSTEM; Seq. Line :; Acq. Instrument : HPLC; Location :; Injection Date : 19-10-2024 14:32:03; Inj :; Sequence File; : F:\HPLC_Projects\Projects\Data\SHIBU SEQUENCE 2024-10-19 13-42-22\SHIBU; SEQUENCE .S; Method; : F:\HPLC_Projects\Projects\Data\SHIBU SEQUENCE 2024-10-19 13-42-22\SHIBU.M; (Sequence Method); Last changed; : 19-10-2024 13:42:19 by SYSTEM; Sorted By; Signal; Multiplier; Dilution; Peak RetTime Type; Width; Area; Height; [min]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

Data File F:\HPLC_Projects\Projects\Data\SHIBU SEQUENCE 2024-10-19 13-42-22\004-P1-A4-4.D
Sample Name: 4

Sample Operator : SYSTEM

Inj Volume : 5.000 µl

DAD1 A, Sig=230,4 Ref=off (004-P1-A4-4.D)

Area Percent Report

Use Multiplier & Dilution Factor with ISTDs

Signal 1: DAD1 A, Sig=230,4 Ref=off

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

HPLC 19-10-2024 14:47:11 SYSTEM | Page | 2 of 2
Peak RetTime Type Width | Area | Height | Area
# | [min] | [min] | [mAU*s] | [mAU] | %

8 | 5.794 VB E 0.3401 144.95007 | 5.41864 | 1.0183
Totals : | 1.22347e4 1090.26718

Signal 2: VWD1 A, Wavelength=250 nm

===================================================================== *** End of Report ***

Peak RetTime Type | Width | Area | Height | Area
# | [min] | [min] | [mAU*s] | [mAU] | %

1 | 2.396 VB R 0.0685 | 35.06844 | 8.25823 | 0.5553
2 | 2.594 BB | 0.0497 | 13.04671 | 4.15262 | 0.2066
3 | 2.714 BV E 0.0479 | 43.27529 | 14.48292 | 0.6853
4 | 3.386 VV R 0.3111 2437.51489 | 96.04060 38.5994
5 | 3.630 VV | 0.2176 | 437.16357 | 25.42423 | 6.9227
6 | 4.274 VV | 0.2534 1140.49646 | 64.14730 18.0604
7 | 4.651 VB | 0.1102 1780.83289 240.96561 28.2005
8 | 5.359 BV | 0.1069 | 189.95071 | 27.06949 | 3.0080
9 | 5.649 VB | 0.3153 | 237.55832 | 11.02898 | 3.7619
Totals : | 6314.90729 491.56998

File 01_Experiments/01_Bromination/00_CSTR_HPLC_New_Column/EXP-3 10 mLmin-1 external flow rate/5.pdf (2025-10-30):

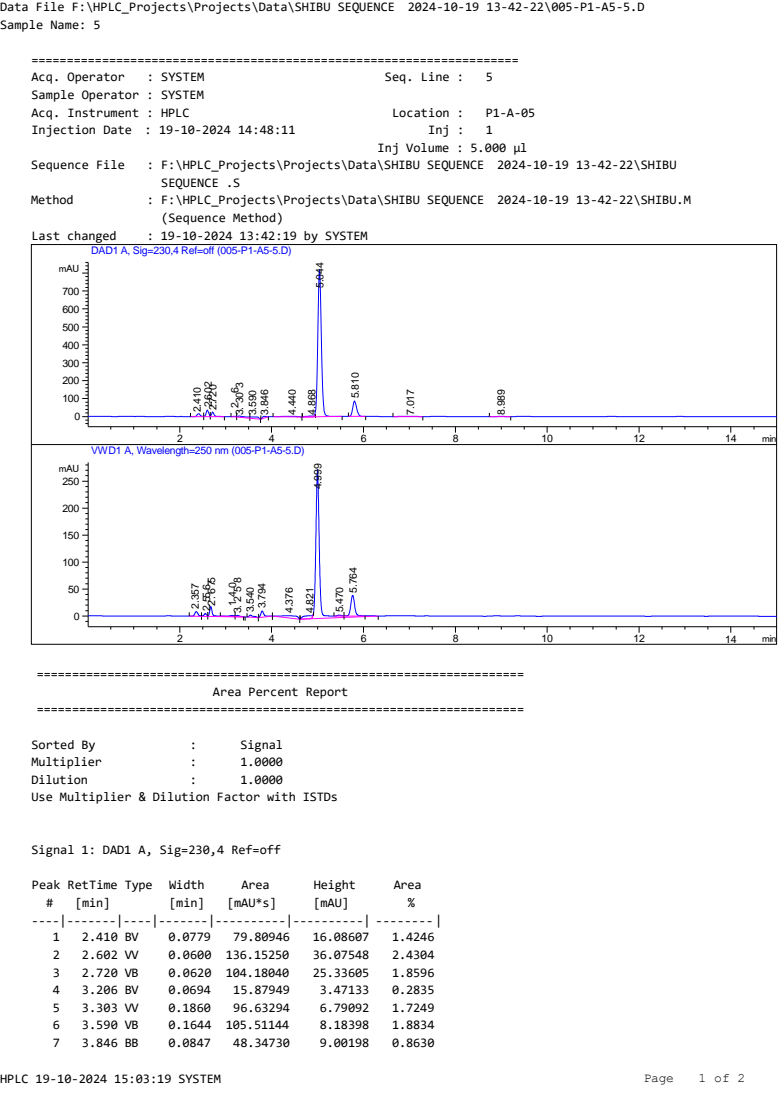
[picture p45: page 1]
HPLC 19-10-2024 15:03:19 SYSTEM; Page; Acq. Operator; : SYSTEM; Seq. Line :; Acq. Instrument : HPLC; Location :; Injection Date : 19-10-2024 14:48:11; Inj :; Sequence File; : F:\HPLC_Projects\Projects\Data\SHIBU SEQUENCE 2024-10-19 13-42-22\SHIBU; SEQUENCE .S; Method; : F:\HPLC_Projects\Projects\Data\SHIBU SEQUENCE 2024-10-19 13-42-22\SHIBU.M; (Sequence Method); Last changed; : 19-10-2024 13:42:19 by SYSTEM; Sorted By; Signal; Multiplier; Dilution; Peak RetTime Type; Width; Area; Height; [min]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

Data File F:\HPLC_Projects\Projects\Data\SHIBU SEQUENCE 2024-10-19 13-42-22\005-P1-A5-5.D
Sample Name: 5

Sample Operator : SYSTEM

Inj Volume : 5.000 µl

DAD1 A, Sig=230,4 Ref=off (005-P1-A5-5.D)

Area Percent Report

Use Multiplier & Dilution Factor with ISTDs

Signal 1: DAD1 A, Sig=230,4 Ref=off

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

HPLC 19-10-2024 15:03:19 SYSTEM | Page | 2 of 2

Signal 2: VWD1 A, Wavelength=250 nm

===================================================================== *** End of Report ***

Peak RetTime Type Width | Area | Height | Area
# | [min] | [min] | [mAU*s] | [mAU] | %

8 | 4.440 BB | 0.3015 | 74.94240 | 3.10555 | 1.3377
9 | 4.868 BV E 0.1493 | 61.94097 | 5.58704 | 1.1057
10 | 5.044 VB R 0.0817 4338.73877 820.46753 77.4474
11 | 5.810 BB | 0.0895 | 502.50720 | 86.87798 | 8.9699
12 | 7.017 BB | 0.1985 | 21.91544 | 1.46494 | 0.3912
13 | 8.989 BB | 0.1761 | 15.61688 | 1.15217 | 0.2788
Totals : | 5602.17519 1023.60102
Peak RetTime Type | Width | Area | Height | Area
# | [min] | [min] | [mAU*s] | [mAU] | %

1 | 2.357 BV | 0.0768 | 39.88468 | 8.34361 | 1.7904
2 | 2.556 VV | 0.0599 | 20.30528 | 5.04901 | 0.9115
3 | 2.675 VV R 0.0679 | 86.00138 | 18.26847 | 3.8606
4 | 3.140 VV E 0.1283 | 15.75979 | 1.72934 | 0.7075
5 | 3.258 VB E 0.0870 | 12.13715 | 1.99513 | 0.5448
6 | 3.540 BB | 0.0932 | 25.20294 | 3.76000 | 1.1314
7 | 3.794 BB | 0.0751 | 58.12955 | 11.66459 | 2.6094
8 | 4.376 BB | 0.3700 | 99.22849 | 3.93816 | 4.4544
9 | 4.821 BV E 0.1713 | 73.81908 | 5.69370 | 3.3137
10 | 4.999 VV R 0.0850 1558.30505 275.62830 69.9523
11 | 5.470 VV E 0.0924 | 10.92176 | 1.78414 | 0.4903
12 | 5.764 VV E 0.0909 | 227.97424 | 38.62965 10.2338
Totals : | 2227.66939 376.48408

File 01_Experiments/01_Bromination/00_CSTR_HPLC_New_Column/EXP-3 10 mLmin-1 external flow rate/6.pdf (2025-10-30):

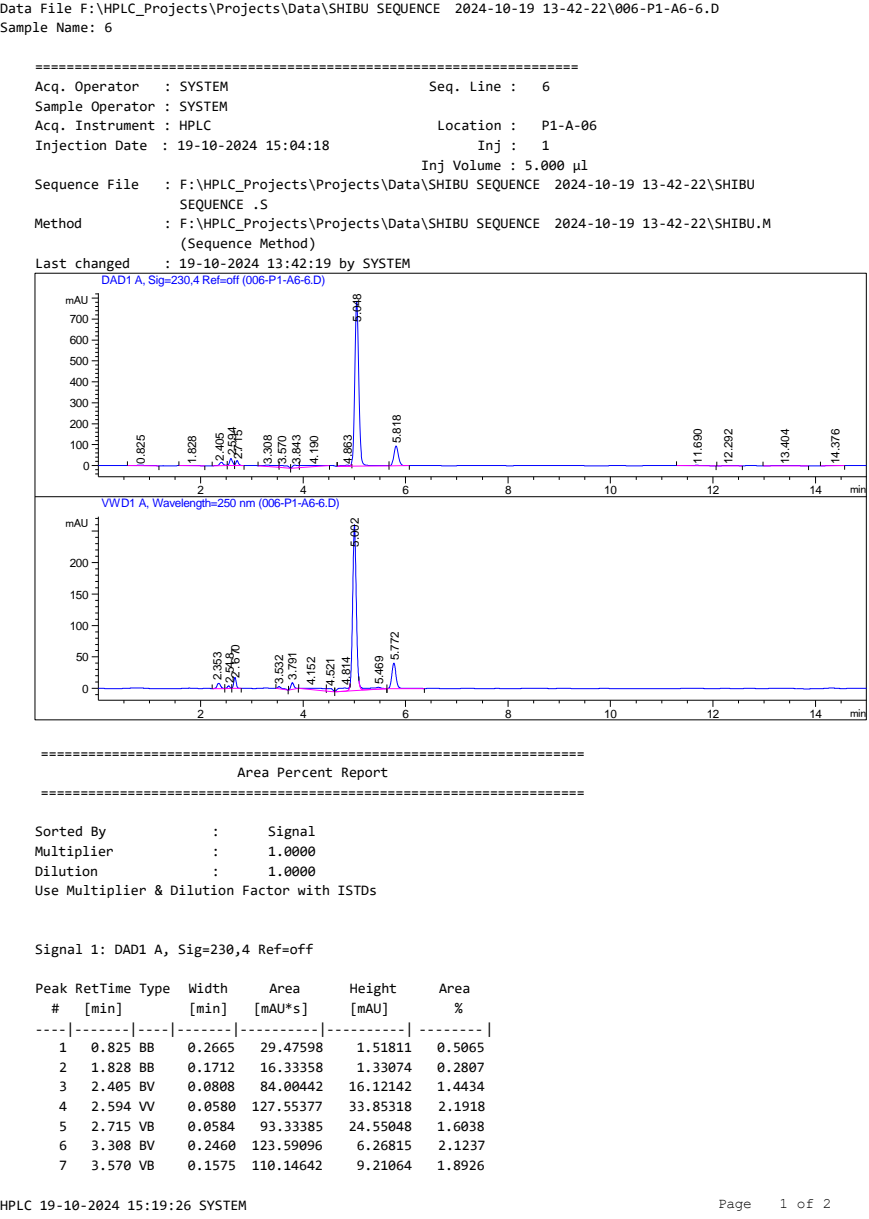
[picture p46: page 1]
HPLC 19-10-2024 15:19:26 SYSTEM; Page; Acq. Operator; : SYSTEM; Seq. Line :; Acq. Instrument : HPLC; Location :; Injection Date : 19-10-2024 15:04:18; Inj :; Sequence File; : F:\HPLC_Projects\Projects\Data\SHIBU SEQUENCE 2024-10-19 13-42-22\SHIBU; SEQUENCE .S; Method; : F:\HPLC_Projects\Projects\Data\SHIBU SEQUENCE 2024-10-19 13-42-22\SHIBU.M; (Sequence Method); Last changed; : 19-10-2024 13:42:19 by SYSTEM; Sorted By; Signal; Multiplier; Dilution; Peak RetTime Type; Width; Area; Height; [min]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

Data File F:\HPLC_Projects\Projects\Data\SHIBU SEQUENCE 2024-10-19 13-42-22\006-P1-A6-6.D
Sample Name: 6

Sample Operator : SYSTEM

Inj Volume : 5.000 µl

DAD1 A, Sig=230,4 Ref=off (006-P1-A6-6.D)

Area Percent Report

Use Multiplier & Dilution Factor with ISTDs

Signal 1: DAD1 A, Sig=230,4 Ref=off

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

HPLC 19-10-2024 15:19:26 SYSTEM | Page | 2 of 2
Peak RetTime Type Width | Area | Height | Area
# | [min] | [min] | [mAU*s] | [mAU] | %

8 | 3.843 BV | 0.1059 | 91.98590 | 13.11008 | 1.5806
9 | 4.190 VB | 0.3643 | 185.05847 | 6.30722 | 3.1799
10 | 4.863 BV E 0.1589 | 53.56673 | 4.43401 | 0.9204
11 | 5.048 VV R 0.0826 4226.56250 788.11615 72.6250
12 | 5.818 VB | 0.0909 | 555.93823 | 94.09657 | 9.5527
13 11.690 BB | 0.2636 | 39.52723 | 1.92488 | 0.6792
14 12.292 BB | 0.1875 | 16.54554 | 1.09960 | 0.2843
15 13.404 BB | 0.3633 | 46.67860 | 1.66405 | 0.8021
16 14.376 BB | 0.1930 | 19.40599 | 1.46041 | 0.3335
Totals : | 5819.70816 1005.06567

Signal 2: VWD1 A, Wavelength=250 nm

===================================================================== *** End of Report ***

Peak RetTime Type | Width | Area | Height | Area
# | [min] | [min] | [mAU*s] | [mAU] | %

1 | 2.353 BV | 0.0745 | 38.88037 | 8.31833 | 1.9682
2 | 2.548 VV | 0.0549 | 15.22134 | 4.23463 | 0.7705
3 | 2.670 VB | 0.0522 | 58.13512 | 17.28532 | 2.9429
4 | 3.532 BB | 0.0861 | 21.29436 | 3.44642 | 1.0780
5 | 3.791 BB | 0.0666 | 46.81354 | 10.78671 | 2.3698
6 | 4.152 BV | 0.3852 | 69.33369 | 2.22704 | 3.5098
7 | 4.521 VB | 0.1180 | 32.91998 | 4.31763 | 1.6665
8 | 4.814 BV E 0.1816 | 66.81949 | 4.76629 | 3.3825
9 | 5.002 VV R 0.0791 1334.23816 263.51550 67.5420
10 | 5.469 VB E 0.2723 | 58.72572 | 2.71547 | 2.9728
11 | 5.772 BV R 0.0892 | 233.03967 | 40.44749 11.7970
Totals : | 1975.42143 362.06082

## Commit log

2025-10-30 initial upload
    [03.3 mL per min.csv, 05 mL per min.csv, 0spv.csv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]
2025-10-30 Added Material Folder and .txt component documentation
    [base_plate.stl, case_RTD_cell_extension.stl, case_master_extension.stl]
2025-10-30 update RTD model to reflect new folder structure
    [03.3 mL per min processed.csv, 05 mL per min processed.csv]
2025-10-31 Update RTD_cell.rst
    Added CAD link to Bricklet Casing
2025-11-04 add materials into documentation
2025-12-21 remove arduino code from software section
2026-01-12 update links to cad files
    [RTD_cell_bottom_1mm_tubing.ipt, RTD_cell_bottom_1mm_tubing.stl, RTD_cell_bottom_2mm_tubing.ipt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]
2026-01-12 change cad file location
    [RTD_cell_bottom_1mm_tubing.ipt, RTD_cell_bottom_1mm_tubing.stl, RTD_cell_bottom_2mm_tubing.ipt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]
2026-06-26 add fit statistics
    [summary_table.csv]
